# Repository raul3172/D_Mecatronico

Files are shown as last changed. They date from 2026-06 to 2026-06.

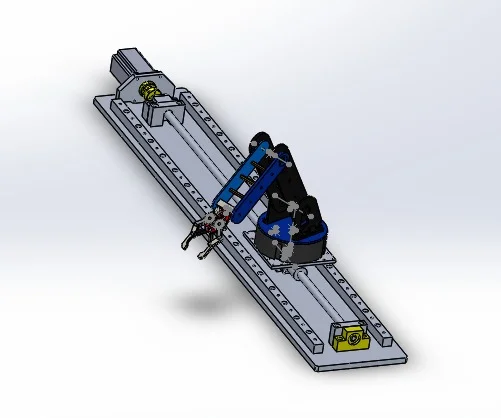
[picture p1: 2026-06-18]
Imagenes/CAD_ROS.webp

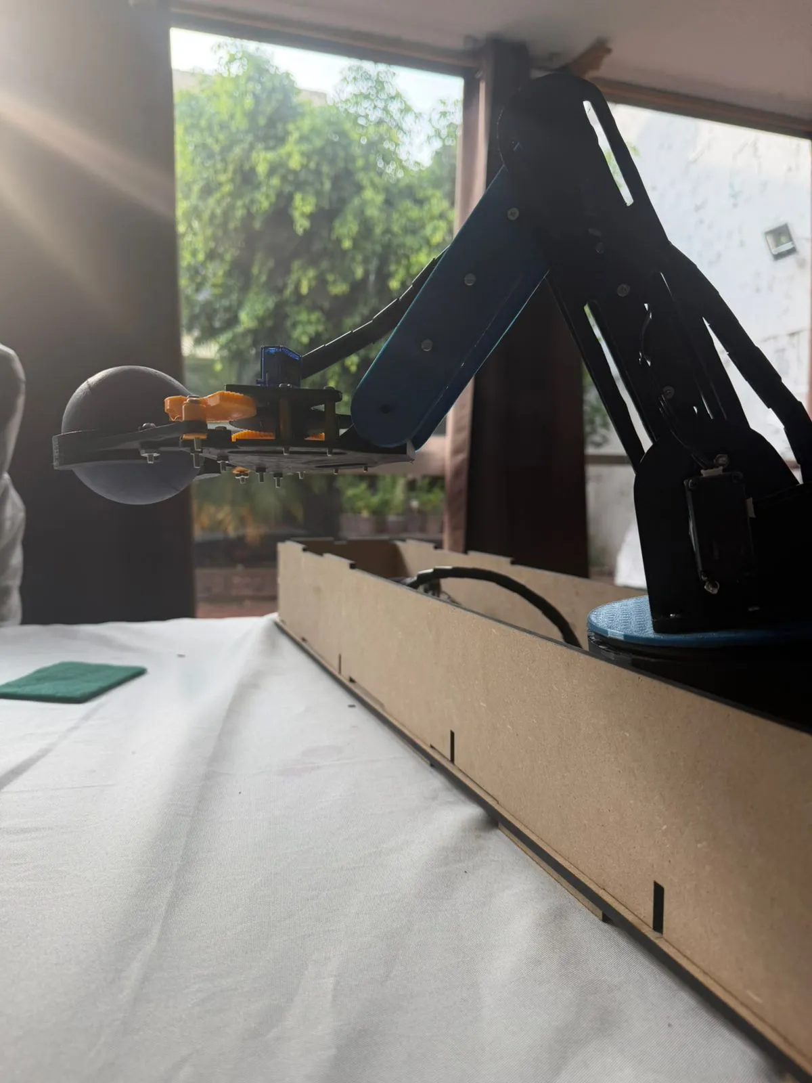
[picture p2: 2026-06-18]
Imagenes/Prototipo.webp

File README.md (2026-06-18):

# Universidad Autónoma de México — Facultad de Ingeniería
## Diseño Mecatrónico
### Brazo Robótico de 4 GDL + Gripper + Base Lineal con Motor a Pasos — Operado en ROS 2
Diseñado y ensamblado por: 
-Fuentes Yañez Ivan
-Garduño Cruz Ingrid Paola
-Huarancca Panana Irvin Daymont
-López Cruz Marino
-Ortíz Martínez Raúl

---

## Tabla de Contenidos

- [Descripción del Proyecto](#descripción-del-proyecto)
- [Arquitectura del Sistema](#arquitectura-del-sistema)
- [Estructura de Archivos](#estructura-de-archivos)
- [Descripción de los Códigos](#descripción-de-los-códigos)
  - [arm_description_v2.xacro](#1-arm_description_v2xacro--descripción-cinemática-del-robot)
  - [arm_controllers.yaml](#2-arm_controllersyaml--configuración-de-controladores)
  - [teach_repeat.py](#3-teach_repeatpy--control-por-terminal-enseñar-y-repetir)
  - [teach_pendant_gui.py](#4-teach_pendant_guipy--interfaz-gráfica-de-control-pyqt5)
  - [IntegradoMotoresYBase.ino](#5-integradomoresybaseino--firmware-esp32-control-de-hardware-real)
- [Interconexión entre Módulos](#interconexión-entre-módulos)
- [Requisitos Previos](#requisitos-previos)
- [Instalación y Configuración](#instalación-y-configuración)
- [Instrucciones para Echar a Andar el Robot](#instrucciones-para-echar-a-andar-el-robot)
- [Control del Robot](#control-del-robot)
- [Solución de Problemas Comunes](#solución-de-problemas-comunes)
- [Notas Técnicas](#notas-técnicas)

---

## Descripción del Proyecto

Este proyecto implementa el control completo de un **brazo robótico serial de 3 grados de libertad (GDL)** montado sobre una **base lineal accionada por motor a pasos**, con un **gripper** al final del efector. El sistema es operado mediante **ROS 2** y puede visualizarse y simularse en **RViz** y **Gazebo**.

### Configuración Física

| Componente | Tipo | Articulación ROS 2 |
|---|---|---|
| Base lineal (riel) | Prismática — traslación en eje Y | `Motor_Base` |
| Hombro | Revoluta | `Motor_1` |
| Codo | Revoluta | `Motor_2` |
| Muñeca | Revoluta | `Motor_3` |
| Gripper | (efector final, no articulado en control) | — |

---

## Arquitectura del Sistema

```
┌─────────────────────────────────────────────────────────────────┐
│                     RASPBERRY PI — ROS 2                        │
│                                                                 │
│  ┌──────────────────┐        ┌───────────────────────────────┐ │
│  │ teach_pendant_   │        │       teach_repeat.py         │ │
│  │    gui.py        │        │   (Control por terminal)      │ │
│  │  (GUI PyQt5)     │        │                               │ │
│  └────────┬─────────┘        └─────────────┬─────────────────┘ │
│           │                                │                   │
│           └───────────────┬────────────────┘                   │
│                           │  publica /joint_states             │
│                           ▼                                    │
│            ┌──────────────────────────┐                        │
│            │     /joint_states topic  │                        │
│            │  sensor_msgs/JointState  │                        │
│            └──────┬───────────────────┘                        │
│                   │                                            │
│        ┌──────────┴──────────┐                                 │
│        ▼                     ▼                                 │
│  ┌──────────────┐    ┌───────────────────┐                     │
│  │ robot_state_ │    │  serial_bridge    │                     │
│  │ publisher    │    │  (nodo ROS 2)     │                     │
│  │ (XACRO/TF)  │    │  espera CALIBRADO │                     │
│  └──────┬───────┘    └────────┬──────────┘                     │
│         │                     │  <riel,h,c,m,g> por UART      │
│         ▼                     │  115200 baud                   │
│  ┌─────────────┐              │                                │
│  │    RViz     │              │                                │
│  │ (simulación)│              │                                │
│  └─────────────┘              │                                │
└───────────────────────────────┼────────────────────────────────┘
                                │  USB/UART serial
                                ▼
┌───────────────────────────────────────────────────────────────┐
│               ESP32 — IntegradoMotoresYBase.ino               │
│                                                               │
│  setup() → ejecutarHoming() → xTaskCreate(tareaMotorPasos)   │
│                                                               │
│  loop() (core 1)              tareaMotorPasos (core 0)        │
│  ├─ Parser serial <...>       └─ stepper.run() + WDT          │
│  └─ procesarTrama()                                           │
│       ├─ moverAMilimetros()  → A4988 → Motor a pasos (riel)  │
│       ├─ radToHiwonder()     → Bus serial → Servos Hiwonder   │
│       │                          ID1:Hombro  ID2:Codo         │
│       │                          ID3:Muñeca                   │
│       └─ servoGripper.write()→ PWM → SG90 (gripper)          │
│                                                               │
│  GPIO 26: FC_INICIO ──── homing                              │
│  GPIO 27: FC_FIN    ──── homing                              │
└───────────────────────────────────────────────────────────────┘
```

---

## Estructura de Archivos

```
robot_arm_ws/
├── src/
│   └── arm_description/
│       ├── urdf/
│       │   └── arm_description_v2.xacro       # Descripción cinemática del robot
│       ├── config/
│       │   └── arm_controllers.yaml           # Configuración de controladores ROS 2
│       ├── launch/
│       │   └── display.launch.py              # Launch para RViz
│       ├── scripts/
│       │   ├── teach_repeat.py                # Control por terminal (enseñar y repetir)
│       │   └── teach_pendant_gui.py           # Control por interfaz gráfica PyQt5
│       ├── meshes/                            # Mallas 3D del robot (.STL/.DAE)
│       ├── package.xml
│       └── CMakeLists.txt
├── firmware/
│   └── IntegradoMotoresYBase/
│       └── IntegradoMotoresYBase.ino          # Firmware ESP32 — control de hardware real
└── README.md
```

---

## Descripción de los Códigos

### 1. `arm_description_v2.xacro` — Descripción Cinemática del Robot

**Propósito:** Define la geometría, cinemática, masa e inercias del robot para ROS 2.

**Contenido principal:**

- **Links** (eslabones): declaran la geometría visual, de colisión y propiedades de masa/inercia de cada pieza física. Las inercias están expresadas en coordenadas **relativas al link**, no globales.
- **Joints** (articulaciones): definen cómo se conectan los links entre sí. Los orígenes están en **metros** y los ángulos en **radianes**.

**Articulaciones definidas:**

| Joint | Tipo | Eje | Rango |
|---|---|---|---|
| `Motor_Base` | `prismatic` | Y | 0.0 – 0.5 m |
| `Motor_1` | `revolute` | Z | −π – +π rad |
| `Motor_2` | `revolute` | Z | −π/2 – +π/2 rad |
| `Motor_3` | `revolute` | Z | −π – +π rad |

> **Nota importante:** Los archivos exportados desde CAD frecuentemente usan milímetros en lugar de metros y coordenadas globales en los orígenes de inercia. Esta versión (`v2`) corrige ambos problemas.

---

### 2. `arm_controllers.yaml` — Configuración de Controladores

**Propósito:** Configura el plugin `ros2_control` para exponer los cuatro joints del robot como un `JointTrajectoryController`.

**Estructura:**

```yaml
controller_manager:
  ros__parameters:
    joint_state_broadcaster:
      type: joint_state_broadcaster/JointStateBroadcaster

    arm_controller:
      type: joint_trajectory_controller/JointTrajectoryController

arm_controller:
  ros__parameters:
    joints:
      - Motor_Base
      - Motor_1
      - Motor_2
      - Motor_3
    command_interfaces: [position]
    state_interfaces: [position, velocity]
```

**Por qué los cuatro joints:** Una configuración incompleta (solo 3 joints) haría que `ros2_control` ignorara `Motor_Base`, dejando la base lineal sin control activo.

---

### 3. `teach_repeat.py` — Control por Terminal (Enseñar y Repetir)

**Propósito:** Nodo ROS 2 en Python que permite al usuario definir posturas del robot ("enseñar") mediante comandos de terminal y luego reproducirlas en secuencia ("repetir").

**Funcionamiento interno:**

```
Usuario escribe postura → Nodo recibe parámetros →
Publica en /joint_states → ros2_control ejecuta movimiento
```

**Características clave:**

- Usa un `dict` (`_pos_map`) para mapear nombre de joint → posición, en lugar de índices fijos. Esto lo hace **robusto ante mensajes `JointState` que lleguen en orden arbitrario**.
- Permite guardar una secuencia de waypoints y reproducirlos en bucle.
- Las posiciones de `Motor_Base` se especifican en **metros** y las de `Motor_1/2/3` en **radianes**.

**Uso básico:**

```bash
ros2 run arm_description teach_repeat.py
# Dentro del nodo:
# > teach   → guarda postura actual
# > repeat  → reproduce todas las posturas guardadas
# > clear   → borra la secuencia
```

---

### 4. `teach_pendant_gui.py` — Interfaz Gráfica de Control (PyQt5)

**Propósito:** Nodo ROS 2 con interfaz gráfica que emula un *teach pendant* industrial: panel de control con sliders para mover cada articulación en tiempo real.

**Funcionamiento interno:**

```
Slider GUI (PyQt5) → callback onChange →
Publica JointState en /joint_states →
robot_state_publisher actualiza TF →
RViz visualiza postura
```

**Características de la GUI:**

| Control | Rango | Unidad |
|---|---|---|
| Slider `Motor_Base` | 0.0 – 0.5 | metros (m) |
| Slider `Motor_1` | −3.14 – +3.14 | radianes (rad) |
| Slider `Motor_2` | −1.57 – +1.57 | radianes (rad) |
| Slider `Motor_3` | −3.14 – +3.14 | radianes (rad) |
| Botón **Teach** | — | Guarda postura actual |
| Botón **Repeat** | — | Reproduce secuencia |
| Botón **Clear** | — | Limpia secuencia |

> Los sliders usan escala interna en enteros y convierten al rango físico al publicar, garantizando precisión y fluidez visual.

---

### 5. `IntegradoMotoresYBase.ino` — Firmware ESP32: Control de Hardware Real

**Propósito:** Firmware que corre directamente en el microcontrolador **ESP32** y actúa como la capa más baja del sistema. Recibe tramas de posición desde la Raspberry Pi (vía `serial_bridge` de ROS 2) y las traduce en movimientos físicos reales de todos los actuadores.

> Este archivo es el **puente entre el mundo ROS 2 (software) y el hardware físico del robot**. Sin él, el sistema solo funciona en simulación.

---

#### Mapa de hardware

| GPIO | Periférico | Función |
|---|---|---|
| 16 (RX2) | Bus serial Hiwonder | Recibir telemetría de servos |
| 17 (TX2) | Bus serial Hiwonder | Enviar comandos a servos |
| 18 | Servo SG90 (gripper) | PWM 50 Hz, 500–2400 µs |
| 25 | Driver A4988 — DIR | Dirección del motor a pasos |
| 33 | Driver A4988 — STEP | Pulsos del motor a pasos |
| 26 | Final de carrera INICIO | Detecta el límite de origen del riel |
| 27 | Final de carrera FIN | Detecta el límite máximo del riel |

---

#### Librerías utilizadas

| Librería | Propósito |
|---|---|
| `LobotSerialServoControl` | Protocolo de bus serial para servos Hiwonder (ID 1, 2, 3) |
| `AccelStepper` | Control suave del motor a pasos con aceleración y desaceleración |
| `ESP32Servo` | Generación de PWM para servo SG90 compatible con ESP32 |
| FreeRTOS (integrado en ESP-IDF) | Multitarea: tarea dedicada al motor en core 0 |

---

#### Flujo de ejecución

```
Encendido del ESP32
       │
       ▼
setup()
  ├─ Inicializa serial, GPIO, servo, stepper y mutex
  └─ ejecutarHoming()          ← bloquea hasta completar calibración
          │
          ├─ Fase 1: avanza hasta FC_FIN  → mide recorrido total
          ├─ Retroceso 3 mm (suelta sensor)
          ├─ Fase 2: regresa hasta FC_INICIO → define posición 0
          ├─ Avance 2 mm (despega del sensor) → redefine cero real
          ├─ Test gripper (0° → 110° → 0°)
          └─ Envía "CALIBRADO" por serial → Raspberry Pi libera ROS 2
               │
               ▼
       xTaskCreatePinnedToCore(tareaMotorPasos, core 0)
               │
               ▼
loop() — core 1 (en paralelo con la tarea)
  └─ Lee serial byte a byte buscando tramas <...>
       └─ procesarTrama() cuando trama válida
```

---

#### Secuencia de Homing — `ejecutarHoming()`

El homing es la **calibración automática de la base lineal** al encender el robot. Es indispensable porque el motor a pasos no tiene encoder: sin homing, el ESP32 no sabe en qué posición está el carro del riel.

```
  INICIO ◄────────────────────────────────────────── FIN
  [FC_INICIO]  2mm ◄── cero real ──► 3mm  [FC_FIN]
     │                                              │
     │← ← ← ← Fase 2: regresa ← ← ← ← ← ← ← ← ←│
     │                                              │
     │─ ─ ─ ─ Fase 1: avanza ─ ─ ─ ─ ─ ─ ─ ─ ─ →│
```

**Pasos detallados:**

1. **Avanza hacia FC_FIN** a velocidad constante (300 pasos/s). Mide cuántos pasos recorre — ese valor es `recorridoMaxPasos`, el límite físico del riel.
2. **Retrocede 3 mm** para soltar el sensor final (evita presión mecánica continua).
3. **Regresa hacia FC_INICIO** a velocidad constante inversa.
4. **Define `currentPosition = 0`** al tocar el inicio.
5. **Avanza 2 mm** para despegar el sensor, luego **redefine ese punto como el nuevo cero**. De esta forma el riel nunca queda presionando un final de carrera.
6. **Test del gripper**: ciclo 0° → 110° → 0° para verificar que el SG90 responde correctamente.
7. **Envía `"CALIBRADO"`** por serial. El `serial_bridge` en la Raspberry Pi espera este mensaje antes de comenzar a enviar tramas de posición, garantizando que ROS 2 y el ESP32 están sincronizados.

> **Decisión de diseño crítica:** La tarea FreeRTOS del motor se crea **después** del homing, no antes. Si se creara antes, la tarea y `ejecutarHoming()` competirían por el stepper simultáneamente (race condition), causando movimientos erráticos o bloqueos del mutex.

---

#### Protocolo de comunicación serial — Formato de trama

La Raspberry Pi envía tramas a **115200 baud** con la siguiente estructura:

```
<riel_m,hombro_rad,codo_rad,muneca_rad,gripper_norm>
```

| Campo | Tipo | Unidad | Ejemplo |
|---|---|---|---|
| `riel_m` | float | metros | `0.235` |
| `hombro_rad` | float | radianes | `1.047` |
| `codo_rad` | float | radianes | `-0.524` |
| `muneca_rad` | float | radianes | `0.000` |
| `gripper_norm` | float | normalizado [0.0–1.0] | `0.750` |

**Ejemplo de trama completa:**
```
<0.235,1.047,-0.524,0.000,0.750>
```

El parser en `loop()` detecta `<` para abrir y `>` para cerrar la trama, valida que tenga exactamente **4 comas** y usa `sscanf()` para parsear los 5 valores flotantes de forma robusta. Tramas malformadas o con ruido se descartan silenciosamente.

**Mecanismo de timeout de trama:** Si transcurren más de 50 ms entre `<` y `>` sin cerrar la trama, el buffer se descarta y se espera la siguiente. Esto protege contra fragmentación del stream serial.

---

#### Flush post-homing — `tramasFlushPendientes`

El `serial_bridge` de ROS 2 opera a ~50 tramas/segundo de forma continua. Durante el homing, ROS 2 sigue enviando la posición objetivo inicial (típicamente `0.46 m` de riel), aunque el robot aún no está calibrado. Si el ESP32 procesara esas tramas residuales inmediatamente después del homing, el motor intentaría ir a `0.46 m` antes de que ROS 2 actualizara su estado.

**Solución:** Se descartan las primeras **150 tramas** post-homing (≈ 3 segundos), suficiente para que ROS 2 termine de procesar la trayectoria de calibración y comience a enviar posiciones válidas.

```cpp
if (tramasFlushPendientes > 0) {
    tramasFlushPendientes--;
    return;   // descarta la trama silenciosamente
}
```

---

#### Conversión de unidades — `radToHiwonder()`

Los servos Hiwonder usan una escala propietaria de **0 a 1000** (donde 500 = centro = 0°). La función convierte radianes a esta escala considerando el límite mecánico de ±120° (±2.0944 rad):

```cpp
int radToHiwonder(float rad) {
    return constrain(500 + (int)(rad * 500.0f / LIM_RAD), 0, 1000);
}
```

| Entrada (rad) | Salida (Hiwonder) | Ángulo físico |
|---|---|---|
| −2.0944 | 0 | −120° (límite izquierdo) |
| 0.0 | 500 | 0° (centro) |
| +2.0944 | 1000 | +120° (límite derecho) |

---

#### Deadband de servos

Para evitar vibraciones y desgaste prematuro de los servos Hiwonder por ruido en la señal de ROS 2, se aplica un **deadband de 4 unidades**: solo se envía un nuevo comando al servo si la posición destino difiere en más de 4 unidades de la última enviada.

```cpp
if (abs(posHombro - lastHombro) > DEADBAND) {
    BusServo.LobotSerialServoMove(ID_HOMBRO, posHombro, MOVE_TIME_MS);
    lastHombro = posHombro;
}
```

---

#### Multitarea FreeRTOS — `tareaMotorPasos()`

El motor a pasos requiere pulsos de STEP muy frecuentes (cada pocos microsegundos a alta velocidad). Si estos pulsos se generaran en `loop()` junto con el parsing serial, las interrupciones del serial retrasarían los pulsos y el motor perdería pasos.

**Solución:** La función `stepper.run()` corre en una **tarea dedicada en el core 0** del ESP32 (core independiente al de `loop()`). El acceso al objeto `stepper` está protegido por un **mutex FreeRTOS** (`stepperMutex`) para evitar que `loop()` y la tarea modifiquen el stepper simultáneamente.

```
Core 0                          Core 1
──────────────────────          ──────────────────────
tareaMotorPasos()               loop()
  └─ stepper.run()                └─ Serial.read()
     (pulsos STEP)                   procesarTrama()
     mutex protege acceso            mutex protege acceso
```

La tarea también alimenta el **Watchdog Timer (WDT)** del core 0 en cada iteración con `esp_task_wdt_reset()`, previniendo reinicios del ESP32 por timeout del watchdog.

---

#### Gripper SG90 — Escala normalizada

El gripper recibe valores normalizados `[0.0, 1.0]` desde ROS 2, que se mapean a `[0°, 110°]` del servo SG90:

```cpp
int grados = constrain((int)round(valores[4] * 110.0f), 0, 180);
servoGripper.write(grados);
```

| Valor ROS 2 | Ángulo SG90 | Estado gripper |
|---|---|---|
| `0.0` | 0° | Cerrado |
| `0.5` | 55° | Medio abierto |
| `1.0` | 110° | Abierto total |

---

#### Instrucciones para cargar el firmware

**Requisitos:**
- Arduino IDE 2.x con soporte para ESP32 (board: `esp32 by Espressif Systems`)
- Librerías instaladas en Arduino IDE:
  - `AccelStepper` (Mike McCauley)
  - `ESP32Servo` (Kevin Harrington)
  - `LobotSerialServoControl` (Lobot / Hiwonder) — instalar manualmente

**Pasos:**

```
1. Abrir Arduino IDE
2. Seleccionar placa: Herramientas → Placa → ESP32 Dev Module
3. Seleccionar puerto: Herramientas → Puerto → /dev/ttyUSB0 (o el que corresponda)
4. Abrir IntegradoMotoresYBase.ino
5. Verificar (Ctrl+R) — debe compilar sin errores
6. Subir (Ctrl+U) — mantener presionado BOOT en el ESP32 si no sube automáticamente
7. Abrir Monitor Serial a 115200 baud
8. Verificar que aparezca "ESP32 ONLINE - Iniciando homing automatico..."
9. Observar secuencia de homing; al final debe aparecer "CALIBRADO"
```

> **Importante:** El `serial_bridge` de ROS 2 (en la Raspberry Pi) **espera el mensaje `"CALIBRADO"`** antes de comenzar a publicar tramas. Si el homing falla o el mensaje no llega, el sistema ROS 2 permanece en espera.

---

## Interconexión entre Módulos

El siguiente diagrama muestra el flujo de datos completo entre todos los archivos del proyecto, desde la interfaz de usuario hasta los actuadores físicos:

```
teach_pendant_gui.py  ──┐
teach_repeat.py         ├──► /joint_states topic
                        │         │
                        │         ├──► robot_state_publisher ──► /tf ──► RViz
                        │         │         (arm_description_v2.xacro)
                        │         │
                        │         └──► serial_bridge (nodo ROS 2)
                        │                   │
                        │         arm_controllers.yaml
                        │         (configura JointTrajectoryController)
                        │
                        └──────────────────────────────────────────────────────┐
                                                                               │
                                                               UART 115200 baud│
                                                                               ▼
                                                         IntegradoMotoresYBase.ino (ESP32)
                                                               │
                                      ┌────────────────────────┼──────────────────────────┐
                                      ▼                        ▼                          ▼
                               A4988 + Stepper          Bus Hiwonder               PWM SG90
                               (riel lineal)      (hombro, codo, muñeca)          (gripper)
```

**Flujo de comunicación paso a paso:**

1. `arm_description_v2.xacro` es parseado al arrancar `robot_state_publisher`, definiendo la geometría y los frames TF del robot.
2. El ESP32 ejecuta el homing automático al encender y envía `"CALIBRADO"` por serial cuando termina.
3. El `serial_bridge` de ROS 2 (en la Raspberry Pi) espera `"CALIBRADO"` antes de empezar a enviar tramas de posición.
4. `teach_repeat.py` o `teach_pendant_gui.py` publican mensajes `sensor_msgs/JointState` en `/joint_states`.
5. `robot_state_publisher` consume `/joint_states` y publica las transformadas TF de cada eslabón.
6. **RViz** suscribe a `/tf` y `/robot_description` para renderizar el robot en 3D (simulación visual).
7. El `serial_bridge` también suscribe a `/joint_states` y convierte cada mensaje en una trama `<riel_m,h_rad,c_rad,m_rad,gripper_norm>` que envía al ESP32 por UART.
8. El **ESP32** recibe la trama, la parsea, convierte unidades y envía comandos directos a cada actuador físico.

---

## Requisitos Previos

### Sistema Operativo
- **Raspberry Pi:** Ubuntu 22.04 LTS (recomendado para ROS 2 Humble)
- **PC de desarrollo / Arduino IDE:** Windows, macOS o Linux

### Software — Capa ROS 2 (Raspberry Pi)
- **ROS 2 Humble Hawksbill** (o superior)
- **Python 3.10+**
- **PyQt5** (para la GUI)
- **Gazebo Fortress** o **Ignition** (para simulación)
- **colcon** (herramienta de compilación de ROS 2)

### Software — Firmware ESP32
- **Arduino IDE 2.x**
- Board support: `esp32 by Espressif Systems` (vía Boards Manager)
- Librerías Arduino:
  - `AccelStepper` (Mike McCauley) — Library Manager
  - `ESP32Servo` (Kevin Harrington) — Library Manager
  - `LobotSerialServoControl` (Hiwonder) — instalación manual desde `.zip`

### Instalación de dependencias ROS 2

```bash
sudo apt update && sudo apt install -y \
    python3-colcon-common-extensions \
    ros-humble-robot-state-publisher \
    ros-humble-joint-state-publisher \
    ros-humble-joint-state-publisher-gui \
    ros-humble-ros2-control \
    ros-humble-ros2-controllers \
    ros-humble-xacro \
    ros-humble-rviz2 \
    python3-pyqt5
```

### Permisos de puerto serial (para comunicación con ESP32)

```bash
sudo usermod -a -G dialout $USER
# Cerrar sesión y volver a entrar para que aplique
```

---

## Instalación y Configuración

### 1. Crear el workspace

```bash
mkdir -p ~/robot_arm_ws/src
cd ~/robot_arm_ws/src
```

### 2. Clonar o copiar el paquete

```bash
# Si tienes el repositorio en GitHub:
git clone https://github.com/<tu_usuario>/arm_description.git

# O copia manualmente la carpeta arm_description/ dentro de src/
```

### 3. Instalar dependencias de ROS 2

```bash
cd ~/robot_arm_ws
rosdep install --from-paths src --ignore-src -r -y
```

### 4. Compilar el workspace

```bash
cd ~/robot_arm_ws
colcon build --symlink-install
```

### 5. Cargar el entorno

```bash
source ~/robot_arm_ws/install/setup.bash

# Agrega esta línea a tu ~/.bashrc para no repetirla cada sesión:
echo "source ~/robot_arm_ws/install/setup.bash" >> ~/.bashrc
```

---

## Instrucciones para Echar a Andar el Robot

Abre **cuatro terminales** separadas. En cada una ejecuta `source ~/robot_arm_ws/install/setup.bash` antes de cualquier comando.

---

### Terminal 1 — Publicar la Descripción del Robot

```bash
source ~/robot_arm_ws/install/setup.bash

ros2 launch arm_description display.launch.py
```

Esto inicia:
- `robot_state_publisher` (carga el XACRO y publica `/robot_description`)
- `RViz` (abre la visualización 3D del brazo)

> Verifica en RViz que el robot aparezca correctamente en el panel 3D. Si ves errores de TF, espera unos segundos a que los demás nodos levanten.

---

### Terminal 2 — Iniciar el Controlador de Joints

```bash
source ~/robot_arm_ws/install/setup.bash

ros2 run controller_manager spawner arm_controller
ros2 run controller_manager spawner joint_state_broadcaster
```

O si usas el launch completo con Gazebo:

```bash
ros2 launch arm_description gazebo.launch.py
```

---

### Terminal 3 — Opción A: Control por Terminal

```bash
source ~/robot_arm_ws/install/setup.bash

ros2 run arm_description teach_repeat.py
```

Comandos disponibles dentro del nodo:

| Comando | Acción |
|---|---|
| `teach` | Guarda la postura actual en la secuencia |
| `repeat` | Reproduce todas las posturas guardadas |
| `clear` | Borra la secuencia de posturas |
| `set <joint> <valor>` | Mueve un joint a una posición específica |

Ejemplo de sesión:

```
> set Motor_Base 0.2
> set Motor_1 1.57
> set Motor_2 -0.5
> teach
> set Motor_1 0.0
> set Motor_2 0.0
> teach
> repeat
```

---

### Terminal 3 — Opción B: Control por Interfaz Gráfica (Teach Pendant)

```bash
source ~/robot_arm_ws/install/setup.bash

ros2 run arm_description teach_pendant_gui.py
```

Se abrirá la ventana de la GUI con:
- **4 sliders** para mover cada articulación en tiempo real
- **Botones Teach / Repeat / Clear** para programar movimientos
- Indicadores numéricos del valor actual de cada joint

> Mueve los sliders y observa el robot actualizarse en RViz simultáneamente.

---

### Terminal 4 — Monitoreo (Opcional)

```bash
# Ver todos los topics activos
ros2 topic list

# Ver los estados de los joints en tiempo real
ros2 topic echo /joint_states

# Ver el árbol de transformadas TF
ros2 run tf2_tools view_frames
```

---

## Solución de Problemas Comunes

### El robot no aparece en RViz
- Verifica que `robot_state_publisher` esté corriendo: `ros2 node list | grep robot_state`
- Asegúrate de que el XACRO no tenga errores: `xacro arm_description_v2.xacro`
- En RViz, confirma que el **Fixed Frame** esté configurado como `base_link` o `world`

### Error: "Could not load description" al parsear el XACRO
- El error más común es tener valores en **milímetros** en lugar de **metros**. Revisa que todos los `<origin xyz="..."/>` usen valores menores a 2.0 para un robot de tamaño normal de laboratorio.
- Las inercias deben estar en coordenadas relativas al link, no globales.

### Los joints no responden al publicar en `/joint_states`
- Verifica que `arm_controllers.yaml` liste los **cuatro joints**: `Motor_Base`, `Motor_1`, `Motor_2`, `Motor_3`.
- Confirma que el controlador esté activo: `ros2 control list_controllers`

### La GUI se abre pero el robot no se mueve
- Verifica que el nodo `robot_state_publisher` esté corriendo en otra terminal.
- Confirma que `/joint_states` tenga publicaciones: `ros2 topic hz /joint_states`

### Error de importación de PyQt5
```bash
pip3 install PyQt5
# o bien:
sudo apt install python3-pyqt5
```

### El ESP32 no aparece como puerto serial
```bash
# Verificar que el sistema detecta el dispositivo
lsusb | grep -i "cp210\|ch340\|ftdi"
ls /dev/ttyUSB*

# Si no aparece, instalar el driver CP2102 (chip USB-UART del ESP32)
sudo apt install linux-modules-extra-$(uname -r)
```

### El homing no termina / el motor no se mueve
- Verificar conexión física de DIR (GPIO 25) y STEP (GPIO 33) al A4988.
- Confirmar que el A4988 tiene tensión de referencia de motor (VMOT) y lógica (VDD) correctas.
- Abrir Monitor Serial a 115200 baud y verificar que aparezca `"HOMING: Iniciando..."`.
- Si el motor zumba pero no gira, la corriente del A4988 puede estar demasiado baja — ajustar el potenciómetro del driver.

### El ESP32 nunca envía "CALIBRADO"
- Verificar que los finales de carrera estén conectados a GPIO 26 (FC_INICIO) y GPIO 27 (FC_FIN) con `INPUT_PULLUP`.
- Probar los finales de carrera con un multímetro: deben dar continuidad al presionarse.
- Si el riel llega al final de carrera pero el ESP32 no lo detecta, verificar que el sensor sea normalmente abierto (NA) — el código espera que el pin lea `HIGH` cuando libre y `LOW` al activarse.

### Los servos Hiwonder no responden
- Verificar que el bus serial use GPIO 16 (RX2) y GPIO 17 (TX2) a 115200 baud.
- Confirmar que cada servo tenga su ID configurado correctamente (ID1: hombro, ID2: codo, ID3: muñeca) usando el software de configuración Hiwonder.
- El bus serial Hiwonder es half-duplex: TX y RX del ESP32 se conectan al mismo cable de datos del servo a través de un resistor o lógica de bus.

### El gripper no se mueve o tiembla
- Verificar que el SG90 esté conectado a GPIO 18.
- El servo necesita alimentación de 5V externa — no directamente del ESP32 (que da 3.3V en sus pines GPIO y capacidad de corriente limitada en 5V).
- Si el servo tiembla en posición fija, reducir el ruido en la señal PWM asegurando que la alimentación del servo tenga un capacitor de desacople (100 µF) cerca del conector.

---

## Notas Técnicas

### Conversión de unidades CAD → ROS 2
Los archivos XACRO exportados directamente desde software CAD (SolidWorks, Fusion 360, etc.) frecuentemente tienen:
- Coordenadas en **milímetros** → deben convertirse a **metros** (dividir entre 1000)
- Orígenes de inercia en **coordenadas globales** → deben expresarse en **coordenadas relativas al link**
- Rotaciones de malla visual incorrectas → corregir solo en `<visual>`, **nunca** en `<joint>` para no afectar la cinemática

### Robustez en lectura de JointState
Los mensajes `sensor_msgs/JointState` no garantizan un orden fijo en el arreglo de nombres y posiciones. Por esta razón, los scripts de control usan un **diccionario** (`_pos_map: {nombre_joint: posición}`) en lugar de acceso por índice, garantizando que cada joint reciba el valor correcto independientemente del orden de llegada.

### Escalado del slider de Motor_Base
La articulación prismática `Motor_Base` opera en metros (rango 0.0–0.5 m), mientras que las articulaciones revoluta operan en radianes (±π). La GUI escala internamente los sliders a sus respectivas unidades físicas para garantizar precisión y una experiencia de control natural.

---

## Licencia

Proyecto académico — Universidad Autónoma de México, Facultad de Ingeniería.  
Uso educativo y de investigación.

---

*Desarrollado con ROS 2 Humble · Python 3 · PyQt5 · XACRO · RViz · Gazebo · ESP32 · Arduino IDE · AccelStepper · FreeRTOS*

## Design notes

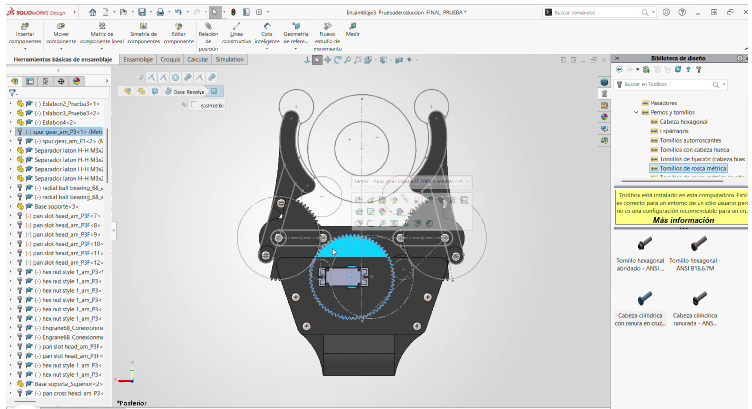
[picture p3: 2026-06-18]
Imagenes/Gripper.webp

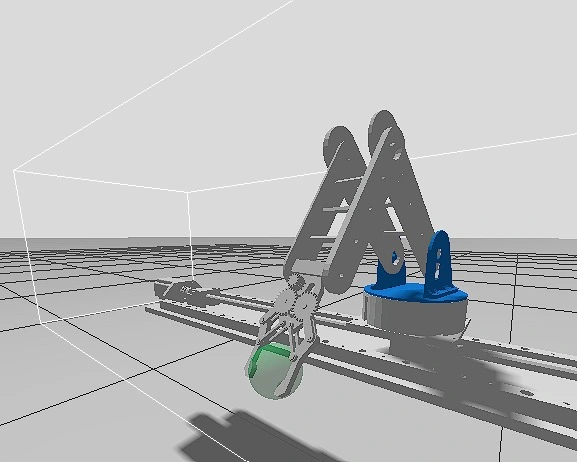
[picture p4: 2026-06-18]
Imagenes/Simulacion.webp

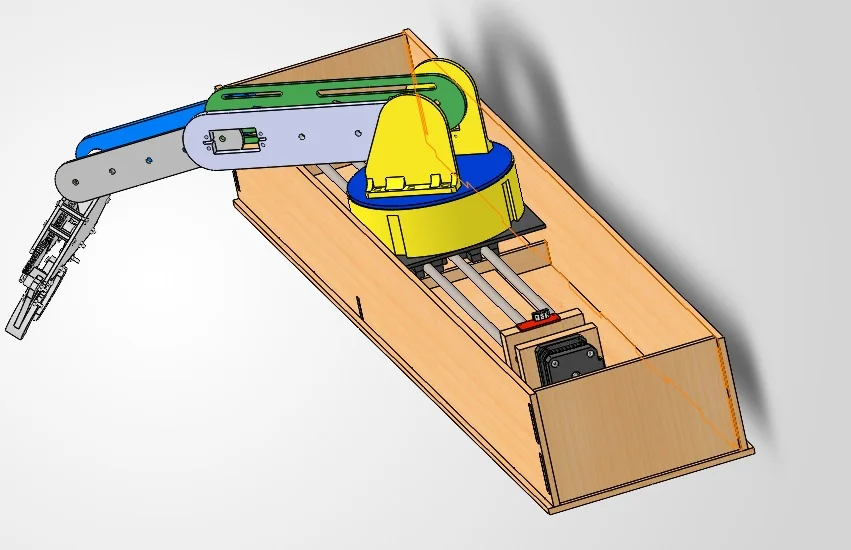
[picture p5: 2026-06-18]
Imagenes/CAD.webp

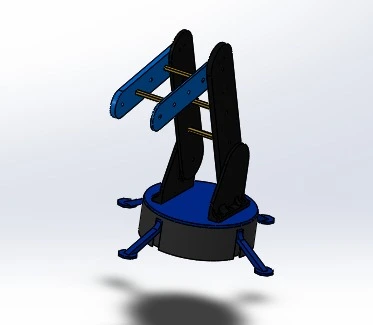
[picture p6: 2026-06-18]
Imagenes/Brazo_CAD.webp

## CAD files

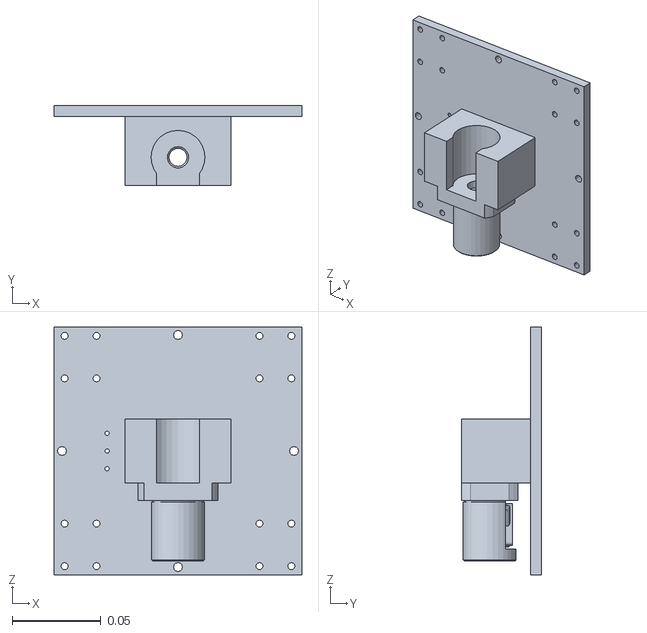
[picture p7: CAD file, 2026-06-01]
src/arm_description/meshes/eje_x.STL
0.14 x 0.0454 x 0.14

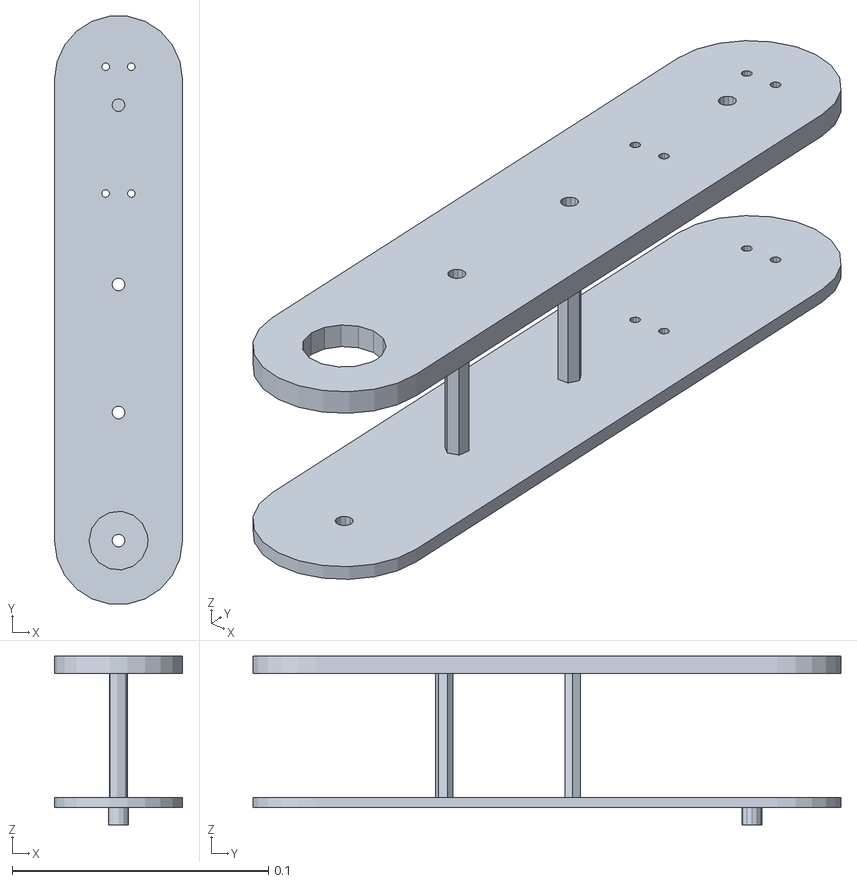
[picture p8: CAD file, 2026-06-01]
src/arm_description/meshes/brazo_base.STL
0.05 x 0.23 x 0.0659

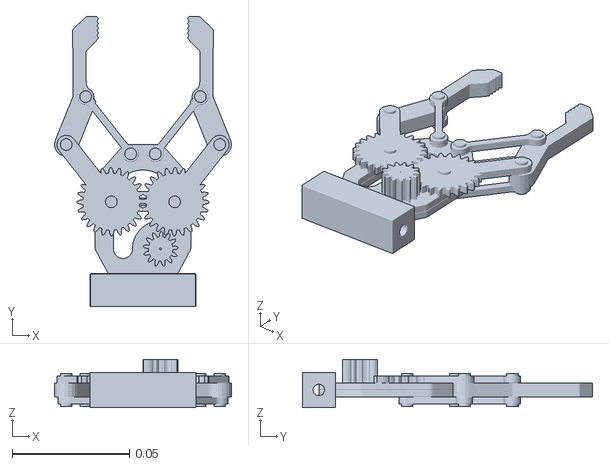
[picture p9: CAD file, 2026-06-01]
src/arm_description/meshes/gripper.STL
0.0753 x 0.123 x 0.0205

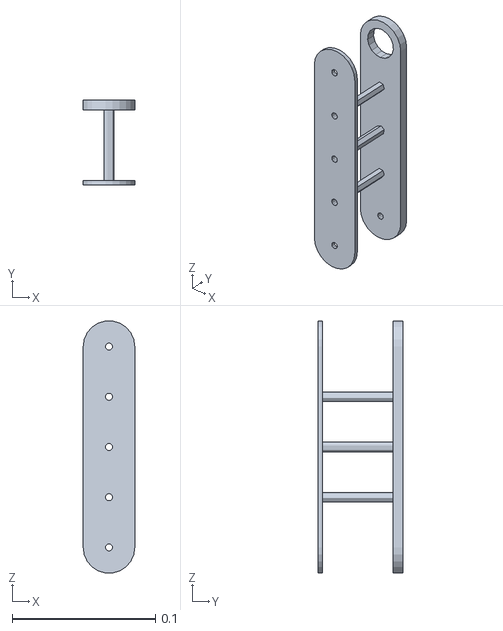
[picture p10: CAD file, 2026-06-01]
src/arm_description/meshes/brazo_gripper.STL
0.036 x 0.0592 x 0.176

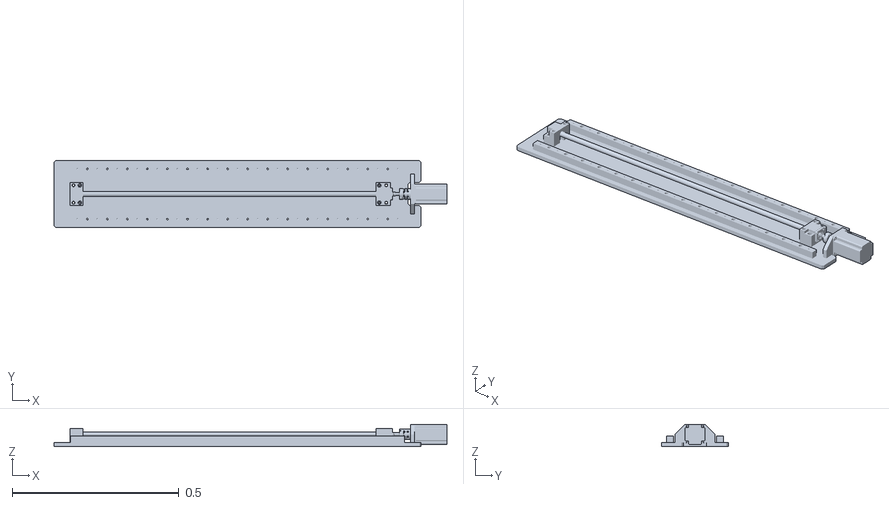
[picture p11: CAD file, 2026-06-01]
src/arm_description/meshes/base_link.STL
1.18 x 0.2 x 0.067

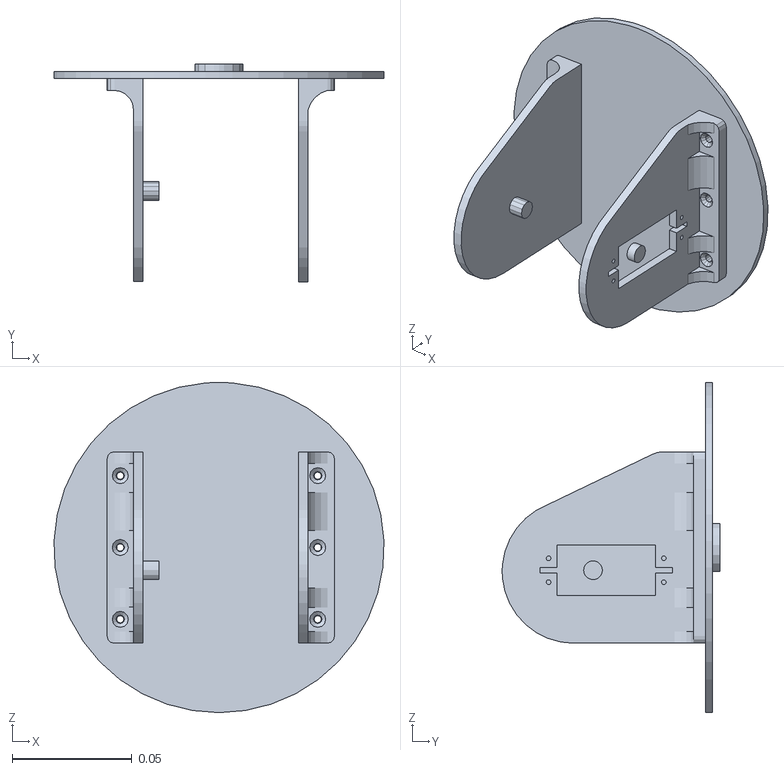
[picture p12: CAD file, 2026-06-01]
src/arm_description/meshes/disco_soportes.STL
0.138 x 0.091 x 0.138

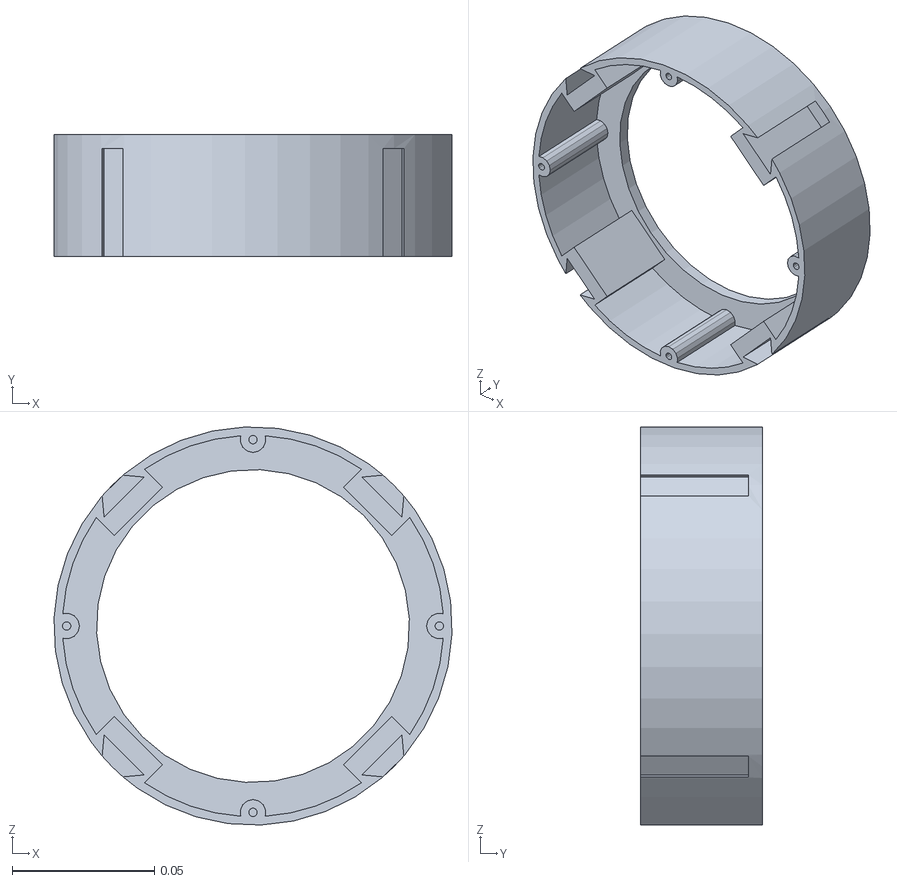
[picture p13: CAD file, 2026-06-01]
src/arm_description/meshes/rotacion_brazo.STL
0.14 x 0.043 x 0.14

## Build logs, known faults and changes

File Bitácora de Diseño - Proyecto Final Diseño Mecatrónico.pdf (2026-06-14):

## Universidad Nacional Autónoma de México

## Facultad de Ingeniería

## División de Ingeniería Mecánica e

## Industrial

## Diseño Mecatrónico

## Grupo 06

## Proyecto Final

## Prototipo de Manipulador Robótico con Base Lineal

## Desplazable

Integrantes:

- Chavez Espinosa Noah Iván
- Cruz Ramírez Dafne Aislinn
- Fuentes Yañez Ivan
- Garduño Cruz Ingrid Paola
- Huarancca Panana Irvin Daymont
- López Cruz Marino
- Ortíz Martínez Raúl
- Rosales Villegas Adair

Profesor: Ing. Ignacio Rangel Fuerte

Semestre 2026-2

### Índice

3.2 Diseño de la Base Lineal: Mecanismo de traslación, guías lineales, y acoplamiento del

3.3 Diseño del Manipulador Robótico (3-DOF): Estructura del brazo, análisis de eslabones y

### 1. Introducción y Definición del Problema

### 1.1 Contexto del Cliente

El presente proyecto surge en respuesta a la creciente necesidad de automatización y optimización en las cadenas de suministro globales. Tomando como caso de estudio y simulacro de aplicación real a los Centros de Distribución de Amazon México, se identificó un área de oportunidad crítica en las estaciones de recepción, clasificación y control de calidad de mercancías.
En un entorno logístico de alta densidad, la velocidad de procesamiento de paquetes y la precisión en la detección de anomalías son factores determinantes para el rendimiento de la planta.

### 1.2 Identificación de Necesidades

Para fundamentar el diseño conceptual bajo la metodología de French, se llevó a cabo un panel de levantamiento de requerimientos entre el Cliente (Representantes operativos de Amazon México), el Ingeniero de Diseño (ID) y el Ingeniero de Automatización (IA). El diálogo técnico permitió estructurar las necesidades del sistema:

- Dinámica Operativa: El cliente externó la urgencia de automatizar el traslado continuo de objetos entre una bandeja de alimentación y una mesa de inspección separadas por una distancia lineal de aproximadamente 30 cm a una altura homóloga, eliminando la manipulación manual que actualmente limita la velocidad de la línea a 20-25 productos por minuto e introduce fallas por fatiga.
- Características de la Carga Útil: El sistema debe poseer la versatilidad de manipular objetos geométricamente diversos de superficies variables (lisas a rugosas), con diámetros nominales concentrados entre los 6 y 8 centímetros, y una masa máxima de diseño de hasta 200 gramos (con capacidad estructural de escalabilidad en etapas iniciales).
- Criterios de Desempeño y Entorno: Se estableció una meta de rendimiento de 20 unidades por minuto con proyección a 30 piezas por minuto en régimen continuo, exigiendo una tolerancia de posicionamiento espacial estricta de ±5 mm. El entorno operativo corresponde a una nave industrial cerrada con temperatura controlada 20∘C a 30∘C y presencia moderada de partículas suspendidas (polvo), requiriendo convivencia segura con operadores humanos y componentes comerciales de fácil sustitución.

### 1.3 Objetivos del Proyecto

- Objetivo General

Diseñar, desarrollar e implementar un prototipo funcional de un manipulador robótico con base lineal desplazable controlado mediante una arquitectura empotrada dual, capaz de emular tareas de inspección de calidad automatizada en un entorno logístico.

- Objetivos Específicos:
1. Desarrollar un sistema de traslación horizontal de alta precisión técnica para la cobertura de un área de trabajo extendida.
2. Diseñar un manipulador articulado de tres grados de libertad (3-DOF) robusto y ligero para el posicionamiento de herramientas de inspección.
3. Implementar un esquema de control distribuido mediante el uso coordinado de una Raspberry Pi 4B (alto nivel / procesamiento) y un microcontrolador ESP32 (bajo nivel / control de actuadores en tiempo real).

### 1.4 Estructura Funcional Global

Siguiendo las directrices del diseño de ingeniería, antes de definir la morfología física del prototipo se estableció la caja negra del sistema, mapeando las transformaciones lógicas desde el estado inicial hasta el estado final del proceso:

- Estado de Entrada: Objeto inerte posicionado en la Estación de Alimentación A.

Diagrama de Flujo de Funciones Internas:

1. Detectar Objeto: Sensado de presencia en la zona de recogida.
2. Sujetar Objeto: Actuación del efector final (gripper) para asegurar la carga sin daño superficial.
3. Transportar Objeto: Activación síncrona del actuador lineal horizontal y las articulaciones angulares del manipulador.
4. Posicionar Objeto: Desaceleración y alineación en la coordenada de destino dentro del margen de tolerancia.
5. Liberar Objeto: Apertura del efector final para deponer la carga.
- Estado de Salida: Objeto posicionado exitosamente en la Estación de Inspección B.

### 2. Especificaciones de Diseño e Ingeniería

### 2.1 Requerimientos del Sistema

Para garantizar el cumplimiento de los objetivos de ingeniería, se estableció una matriz de

especificaciones técnicas categorizadas bajo el enfoque del diseño mecatrónico:

Matriz de especificaciones técnicas

ID | Categoría | Requerimiento Técnico | Métrica / Criterio de Aceptación
REQ-MEC-01 | Mecánica | Estructura del Manipulador | Configuración de 3 Grados de Libertad (Articulado).
REQ-MEC-02 | Mecánica | Sistema de Traslación | Actuador lineal de accionamiento por husillo o banda acoplada.
REQ-ELE-01 | Electrónica | Arquitectura de Control | Control dual jerárquico: Procesamiento en Raspberry Pi 4B y ejecución en ESP32.
REQ-ELE-02 | Electrónica | Regulación de Voltaje | Aislamiento y protección de etapas de potencia mediante convertidores Buck XL4015.
REQ-CTR-01 | Control | Control Lineal | Posicionamiento preciso de la base mediante motor con encoder o lazo abierto de alta resolución (motor a pasos con driver A4988).
REQ-CTR-02 | Control | Control de Articulaciones | Uso de servomotores inteligentes con retroalimentación o comunicación serial activa.

Hoja de Especificaciones Técnicas

Parámetro de Diseño | Valor Marginal Aceptable | Valor Objetivo Ideal
Masa de la Carga Útil | 200 g | 1000 g (Margen de Seguridad)
Distancia de Traslado Horizontal | 30 cm | 50 cm
Precisión de Posicionamiento | ±10 mm | ±5 mm
Tiempo de Ciclo por Unidad | ≤ 3s | ≤ 1s

Límite de Presupuesto | $2,500 MXN | $2,000 MXN
Modo de Operación | Semiautónomo | Automatizado Autónomo Cíclico

### 2.2 Matriz de Selección Alternativas

Para la arquitectura del brazo robótico, el equipo evaluó tres conceptos de diseño bajo un análisis ponderado de criterios técnicos (donde 1 es deficiente y 5 es excelente):

- Concepto A (Manipulador Cartesiano en Base Fija): Alta precisión, pero volumen de trabajo severamente restringido y nula flexibilidad angular.
- Concepto B (Manipulador SCARA): Excelente velocidad para pick-and-place horizontal, pero limitado alcance en el eje vertical Z para inspecciones tridimensionales complejas.
- Concepto C (Manipulador Articulado 3-DOF sobre Actuador Lineal): Seleccionado. Ofrece el mejor compromiso entre volumen de trabajo extendido (gracias al eje lineal horizontal) y versatilidad de orientación de las cámaras o sensores mediante los eslabones rotativos.

Matriz de Selección Alternativas

Criterio de Selección | Peso | Concepto A | Concepto B | Concepto C (Seleccionado)
Espacio de trabajo útil / Alcance | 30% | 2 (0.6) | 3 (0.9) | 5 (1.5)
Destreza y flexibilidad angular | 25% | 1 (0.25) | 3 (0.75) | 4 (1.0)
Facilidad de manufactura y ensamble | 20% | 4 (0.8) | 3 (0.6) | 3 (0.6)
Complejidad de los algoritmos de control | 15% | 5 (0.75) | 4 (0.6) | 3 (0.45)
Costo de implementación de hardware | 10% | 3 (0.3) | 2 (0.2) | 3 (0.3)

Total Ponderado | 100% | 2.70 | 3.05 | 3.85

### 3. Diseño Mecánico y Estructural

### 3.1 Criterios de Selección de Materiales y Manufactura

La determinación del material para los eslabones estructurales del brazo y los carros de la base lineal se sometió a un análisis de compromiso (trade-off) entre rigidez, peso, costo y viabilidad de manufactura:

- Aluminio: Evaluado inicialmente por su excelente resistencia mecánica y nula deflexión ante cargas de flexión. No obstante, se descartó debido a que su elevada densidad incrementaba la inercia rotacional del manipulador, exigiendo torques superiores a los provistos por los servos Hiwonder, aunado al alto costo del material y la necesidad de maquinado CNC externo.
- MDF y Acrílico: Considerados opciones viables debido a su bajo costo y ligereza estructural adecuada para manipular cargas de hasta 200 g. Sin embargo, el tiempo logístico requerido para el corte por láser a través de proveedores externos comprometía el cronograma de entrega del proyecto.
- TPU y PLA (Seleccionados): Se optó de manera definitiva por la combinación de polímeros procesados mediante Manufactura Aditiva (Impresión 3D). El uso de impresoras de tecnología FDM dentro del equipo permitió la fabricación inmediata e iterativa de las piezas. Esta tecnología confirió ventajas estructurales críticas: se configuraron patrones de infarto (infill) internos específicos (como patrones giroidales al 20% o 30%) para optimizar la relación resistencia-peso, reforzando las zonas de alta concentración de esfuerzos (como los alojamientos de los servomotores y los rodamientos MR73 y 1906) sin aumentar el peso total de la estructura móvil.
Componente Estructural | Cantidad | Especificación de Catálogo | Asociación a Plano Técnico
Servomotor Inteligente Hiwonder HTS-35H | 3 | Bus Serial, Torque $\ge$ 15 kg·cm | Servo Hiwonder HTS-35H (Plano)
Ventilador Dual de Enfriamiento | 1 | Cojinete de bolas, 5V DC (25x50mm) | Ventilador dual para Raspberry (Plano)
Rodamiento Rígido de Bolas 1906 | 1 | Diámetro Interno: 6mm | Rodamiento 1906 (Plano)

Rodamiento de Precisión de Bolas MR73 | 2 | Alta velocidad, bajo rozamiento | Rodamiento MR73 (Plano)
Tornillería Allen M3 x 12mm | 16 | Acero aleado, ISO 4762 | Tornillos M3 (Plano)
Tornillería Allen M3 x 20mm | 15 | Acero aleado, ISO 4762 | Tornillos M3 (Plano)
Postes de Soporte Hexagonales (30mm) | 8 | Separador macho-hembra latón/aluminio | Elementos de Fijación (Plano)
Postes de Soporte Hexagonales (20mm) | 8 | Separador macho-hembra latón/aluminio | Elementos de Fijación (Plano)

### 3.2 Diseño de la Base Lineal: Mecanismo de traslación, guías lineales, y

acoplamiento del motor.

Conceptualmente, se consideró usar repuestos de impresoras 3D para armar el riel, ya que ofrecen varias características deseables para el desarrollo del proyecto; la disponibilidad de estos elementos ayudaría a reducir tanto los costos como los tiempos de entrega, mientras que su amplio uso ofrece una amplia documentación que facilitaría el diseño de un riel base usando estos componentes.

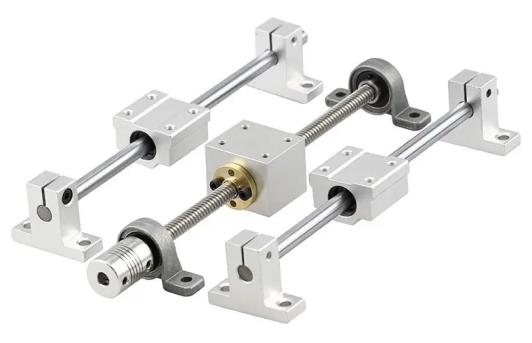
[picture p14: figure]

Figura 1. Propuesta de riel.

Sin embargo, dada la falta de necesidad de personalizar éste elemento en específico, se eligió un riel prefabricado que ya estaba disponible para evitar tiempos de espera y costos extra.

También se consideró brevemente la idea de añadir una ‘mesa’ para cargar con el riel y el brazo. Esta idea fue descartada debido a que era innecesaria.

Figura 2. Propuesta base para el riel.

### 3.3 Diseño del Manipulador Robótico (3-DOF): Estructura del brazo, análisis de

eslabones y articulaciones.

El brazo manipulador está diseñado con 3 grados de libertad (cintura, hombro y codo). La 1ra articulación (cintura) une a la base con la plataforma del riel y le permite rotar sobre el eje Z, otorgando al brazo un rango de manipulabilidad mayor. La 2da articulación (hombro) une al eslabón inferior con la base y permite una rotación sobre el eje X. La 3ra articulación (codo) une al eslabón superior del brazo con el inferior, permite una rotación sobre el eje X e incluye un gripper en el extremo opuesto del eslabón superior.

Figura 3. Ensamble general del manipulador robótico de

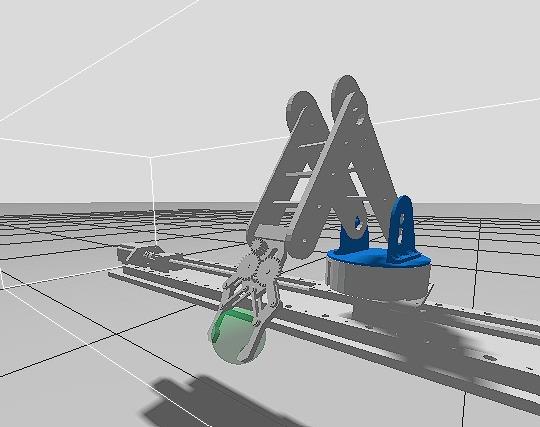
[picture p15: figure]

### 3 GDL y su base lineal de traslación

### 4. Arquitectura de Hardware y Electrónica

### 4.1 Diagrama de Bloques del Sistema. Etapa de Potencia y Regulación

La estabilidad del sistema eléctrico se fundamenta en una estrategia de división de cargas y desacoplamiento de ruidos parásitos. Para garantizar un flujo de corriente continuo y proteger las etapas lógicas contra caídas súbitas de voltaje (brownouts), la red de distribución eléctrica se estructuró a partir de una fuente de alimentación principal de 12V DC distribuida de la siguiente manera:

- Alimentación Directa de 12V: La línea primaria de 12V se rutea de forma directa hacia el bus de alimentación de potencia del driver A4988 (encargado de energizar el motor a pasos del riel lineal) y hacia el bus de alimentación en cascada de los servomotores inteligentes Hiwonder HTS-35H acoplados a las tres articulaciones principales del brazo (Cintura, Hombro y Codo). Esto asegura que la alta demanda de corriente y los picos de torque de los actuadores principales no afecten la instrumentación del sistema.
- Módulo Convertidor Buck XL4015 N.° 1 (Etapa de Cómputo): Se integra un regulador DC-DC Step-Down calibrado a un voltaje de salida constante de 5.0V DC. Este canal se dedica de manera exclusiva a energizar la electrónica digital de control, suministrando la potencia requerida en paralelo por la computadora embebida Raspberry Pi 4B y la placa de desarrollo microcontroladora ESP32.
- Módulo Convertidor Buck XL4015 N.° 2 (Etapa de Efector Final y Seguridad): Se implementa un segundo regulador DC-DC Step-Down aislado, calibrado a una salida regulada de 6.0V DC. Este ramal independiente provee energía dedicada al funcionamiento del motor del efector final (gripper) encargado de la manipulación mecánica de las piezas, aislando magnética y eléctricamente sus conmutaciones lógicas de la etapa de cómputo, alimentando en paralelo las líneas de detección de los interruptores de límite de carrera (limit switches) analógicos situados en los extremos del riel lineal.

### 4.2 Tabla de Componentes (BOM)

A continuación, se tabula el listado consolidado de los elementos del sistema asociados a sus planos mecánicos correspondientes:

Tabla de Componentes Estructurales y Electrónicos

Componente | Cantidad | Referencia de Datasheet | Asociación a Plano Técnico
Raspberry Pi 4B | 1 | RP-008341-DS-1-r | Raspberry PI4B (Plano)
ESP32 (30 Pines, USB-C) | 1 | esp32_datasheet_en.pdf | ESP32 - 30 PINES USB-C (Plano)
Driver A4988 | 1 | A4988_Allegro.pdf | DRIVER A4988 (Plano)
Conversor Buck HW-064 XL4015 | 2 | XL4015_datasheet.pdf | HW-064 XL4015 (Plano)
Hiwonder HTS-35H Servomotores | 3 | HTS-35H_Specifications | Servo Hiwonder HTS-35H (Plano)
Rodamiento Rígido 1906 | 1 | TechnicalSheet-1906 | Rodamiento 1906 (Plano)
Rodamiento de Bolas MR73 | 2 | S1348b09b741a4_MR73 | Rodamiento MR73 (Plano)
Tornillería M3 (12mm / 20mm) | 31 | ISO 4762 Standard | Tornillos M3 (Plano)
Postes de Soporte Metálico | 16 | 30mm y 20mm Hex Spacers | Elementos de Fijación (Plano)

### 4.2 Modelo de Costos de Materiales Directos (BOM Financiero)

El desarrollo del prototipo mecatrónico se rigió bajo una estricta política de optimización presupuestaria, seleccionando componentes comerciales listos para usar (Off-The-Shelf) y procesos de manufactura internos para cumplir con la restricción económica de $2,000.00 MXN establecida en la fase de levantamiento de requerimientos.

Id | Componente / Descripción | Cantidad | Costo Unitario (MXN) | Costo Total (MXN)
1 | Tarjeta de Procesamiento Raspberry Pi 4B | 1 | $0.00* | $0.00
2 | Microcontrolador ESP32 (30 pines, USB-C) | 1 | $140.00 | $140.00
3 | Servomotor Inteligente Hiwonder HTS-35H | 3 | $280.00 | $840.00
4 | Módulo Controlador de Motor a Pasos Driver A4988 | 1 | $45.00 | $45.00
5 | Conversor DC-DC Step-Down Buck XL4015 (5A) | 2 | $65.00 | $130.00
6 | Rodamiento Rígido de Bolas (Modelo 1906) | 1 | $55.00 | $55.00
7 | Rodamiento de Precisión de Bolas MR73 | 2 | $20.00 | $40.00
8 | Filamento TPU / PLA para Impresión 3D (Aprox. 450g) | 1 | $350.00** | $350.00
9 | Kit de Tornillería Metálica M3 (12mm y 20mm) | 31 | $1.50 | $46.50
10 | Postes de Soporte Hexagonales Metálicos (20mm y 30mm) | 16 | $4.00 | $64.00
11 | Sistema de Ventilación Dual 25x50mm para CPU | 1 | $75.00 | $75.00
- | Total Acumulado de Materiales Directos | - | - | $1,785.50

### 5. Arquitectura de Software y Control

La operación del sistema robótico se rige por un entorno de software jerárquico y distribuido que descompone las tareas de planificación global y la ejecución de movimientos físicos. Esta configuración permite procesar los algoritmos computacionales de alto nivel de manera independiente a las rutinas de control deterministas y en tiempo real encargadas de la activación de los actuadores.

### 5.1 Estructura del Repositorio de Control

El entorno de desarrollo y software se centraliza en un espacio de trabajo de ROS2 estructurado bajo el paquete unificado arm_description. Esta organización permite integrar en un mismo repositorio el modelado virtual, los entornos de simulación y los algoritmos de control físico distribuidos en los siguientes directorios raíz:

- /urdf y /meshes: Contienen el archivo descriptivo cinemático y dinámico del robot (arm_description.xacro) junto con los archivos de malla tridimensional (.STL) de cada eslabón (tales como base_link.STL, eje_x.STL, rotacion_brazo.STL y gripper.STL), permitiendo la correcta visualización, mapeo de colisiones e interpretación geométrica en la herramienta Rviz2.
- /config y /launch: Alojan los archivos de parametrización de las articulaciones y perfiles de control (arm_controllers.yaml), así como los scripts de lanzamiento en Python que aíslan los entornos virtuales de prueba (gazebo.launch.py) de la ejecución directa en el hardware real del sistema (real_robot.launch.py).
- /scripts: Módulo crítico de software que ejecuta la lógica operativa del manipulador mediante tres nodos fundamentales programados en Python:
1. serial_bridge.py: Nodo que actúa como puente de comunicación; se suscribe a los tópicos de trayectorias de ROS2, empaqueta los comandos angulares calculados para las articulaciones y las distancias del riel, y los transmite vía puerto serie hacia el microcontrolador ESP32 mediante una trama delimitada.
2. teach_pendant_gui.py: Interfaz gráfica de usuario (GUI) que funge como consola de aprendizaje (Teach Pendant), permitiendo al operador manipular manualmente cada articulación, el riel de traslación y el efector final, facilitando el monitoreo visual del estado de los motores.
3. teach_repeat.py: Nodo encargado de la automatización cíclica, el cual almacena las secuencias de coordenadas y trayectorias previamente grabadas por el usuario para reproducirlas de forma continua, emulando con precisión la rutina operativa en la línea de producción.

### 5.2 Control de Bajo Nivel y Firmware del ESP32

El control determinista y la ejecución física en tiempo real de las trayectorias se coordinan directamente en el microcontrolador ESP32 mediante un firmware estructurado en C++. El sistema opera bajo un esquema de lazo abierto con procesamiento síncrono y decodificación de caracteres guía. La función principal de este firmware consiste en actuar como una capa de abstracción de hardware (Hardware Abstraction Layer o HAL), recibiendo las tramas asíncronas de alta frecuencia desde el nodo puente serial_bridge.py en la Raspberry Pi 4B y traduciendo los valores flotantes directamente en pulsos, comandos por bus serial o señales PWM para excitar los 5 motores del manipulador de forma síncrona.

La secuencia operativa y el procesamiento lógico implementado dentro del script embebido se segmenta detalladamente en los siguientes módulos fundamentales:

### 1. Inicialización y Configuración de Buses de Comunicación (setup)

Al arrancar el sistema, el microcontrolador configura sus periféricos lógicos a través de dos interfaces seriales de hardware independientes:

- Enlace Superior (Computación): El puerto serie por defecto (Serial nativo USB-C) se inicializa a una velocidad de 115,200 baudios. Este canal se vincula directamente al hilo emisor de la Raspberry Pi 4B para capturar la ráfaga de comandos cinemáticos a una tasa de refresco síncrona programada a 300 Hz.
- Enlace Inferior (Actuadores Inteligentes): El segundo puerto de hardware (Serial1) se parametriza de forma asíncrona a 1,000,000 baudios (1 Mbps) empleando los canales GPIO 16 (RX) y GPIO 17 (TX). A través de la librería especializada <SCServo.h>, este bus se conecta directamente a la red en cascada de los servos inteligentes (familia Feetech/Hiwonder STS3215), direccionando las tramas de control en bloque por medio de identificadores físicos precargados (MOTOR_1_ID para el hombro, MOTOR_2_ID para el codo y MOTOR_3_ID para la muñeca).
- Configuración I/O del Riel y Efector: En paralelo, se declaran como salidas digitales estables los pines de control para el driver del actuador lineal (es decir, las señales de dirección DIR y pulsos discretos STEP orientados al circuito integrado A4988), mientras que los pines de entrada asociados a los interruptores de límite axial (limit switches) se configuran con de resistencias de pull-up para atender de manera inmediata las interrupciones de seguridad.

### 2. Algoritmo de Captura y Desempaquetado no Bloqueante (loop)

La rutina cíclica principal ejecuta una evaluación periódica sobre el buffer de entrada del puerto USB para prevenir retardos analógicos. Cuando existen bytes disponibles, el algoritmo lee los caracteres de forma secuencial hasta encontrar un salto de línea ( \n ), utilizando los delimitadores rígidos < y > como firmas de validación estructural.

Una vez que la trama es considerada válida, el firmware ejecuta una subrutina de segmentación por comas (indexOf y substring) aislando dinámicamente las subcadenas para convertirlas a variables numéricas de punto flotante de precisión simple (toFloat()). Este proceso desglosa la cadena recibida en las cinco variables físicas que requiere el manipulador para completar la tarea cinemática:

Trama extraída de /joint_states = (V1, V2, V3, V4, V5

)

Donde de manera estricta:

- V1 = moviento_en_x (Posición deseada del riel de traslación en metros).
- V2 = disco_soportes_rotacion (Ángulo para la articulación del hombro en radianes).
- V3 = brazo_motores (Ángulo para la articulación del codo en radianes).
- V4 = brazo_gripper_azul (Ángulo para la articulación de la muñeca en radianes).
- V5 = gripper_mecanismo (Apertura de la pinza mecánica en radianes).

### 3. Rutinas de Traducción Cinemática y Conducción de Motores

Inmediatamente después de consolidar las variables angulares y lineales, el script invoca la función interna de distribución de movimiento, la cual procesa y discrimina las señales hacia tres etapas físicas diferenciadas que actúan en paralelo:

- Control del Mecanismo del Riel (Actuador Lineal): La variable métrica V1 se procesa mediante un factor de conversión que traduce la distancia a un número absoluto de pasos discretos equivalentes para el motor a pasos, considerando el paso de la banda síncrona o husillo. El firmware evalúa el signo del diferencial respecto a la posición previa para conmutar el estado del pin DIR y genera un bucle temporizado de flancos de subida y bajada en el pin STEP para excitar el driver A4988. Antes de conmutar los flancos, se valida de forma síncrona el estado de los interruptores de límite; si la trayectoria intenta rebasar la cota física permitida, el pulso se inhibe inmediatamente en esa dirección como método de protección contra colisiones mecánicas.
- Control del Brazo Articulado (Servos de Bus Serial): Las variables angulares en radianes correspondientes al hombro (V2), codo (V3) y muñeca (V4) son sometidas a un mapeo lineal matemático para transformarlas a la resolución discreta de los encoders absolutos de los servos (escala nativa de 0 a 4095 pasos, fijando la posición central de 0.0 radianes exactamente en el setpoint intermedio de 2048 pasos). Para asegurar una respuesta fluida y síncrona, las tres posiciones se empaquetan en un arreglo indexado de posición y se transmiten al bus de 1 Mbps utilizando la función nativa de escritura en bloque de la librería Feetech: sts_servos.SyncWritePosEx(ID, 3, Position, Speed, ACC);

Al programar los arreglos de velocidad (Speed) y aceleración (ACC) en valores de cero, el firmware deshabilita las rampas de interpolación internas de los servos, forzándolos a alcanzar el setpoint de forma inmediata y permitiendo que sea la Raspberry Pi 4B (desde el entorno ROS 2) quien gobierne la suavidad del movimiento a través del polinomio cinemático continuo de quinto orden ya calculado.

- Control del Efector Final (Gripper): La última variable desempaquetada V5 se convierte de radianes a un ciclo de trabajo (duty cycle) de modulación por ancho de pulsos (PWM). Esta señal de control se inyecta directamente al servo convencional de la pinza mecánica, modificando la apertura angular de sus mordazas. La limitación por software (constrain) asegura que el gripper ejerza la fuerza necesaria para sujetar firmemente los componentes en el proceso de inspección, evitando rebasar el umbral de deformación o fatiga mecánica sobre la estructura del efector impresa con filamento flexible (TPU).

### 4. Bucle de Retroalimentación de Datos hacia ROS 2 (Feedback Loop)

Finalmente, tras direccionar las señales a los actuadores, el script lee variables internas de estado del microcontrolador o de telemetría de los motores y construye una cadena de texto de confirmación. Esta cadena es transmitida de vuelta a la Raspberry Pi 4B mediante la instrucción Serial.println(), donde el nodo ejecutor serial_bridge.py captura la respuesta asíncrona dentro de su hilo secundario (_read_loop) y la publica de manera inmediata en el tópico de diagnóstico /esp32/feedback, cerrando el ciclo completo de supervisión de hardware.

### 6. Resultados, Conclusiones y Trabajo Futuro

### 6.1 Resultados y Evidencias de Operación

Tras la integración física de los subsistemas, el despliegue del firmware en el microcontrolador ESP32 y la sincronización con el entorno ROS2, se sometió al prototipo a un conjunto de pruebas funcionales en condiciones críticas de operación para validar la estabilidad y velocidad de la arquitectura mecatrónica. En primera instancia, las pruebas de desempeño y sincronización cinemática de alta frecuencia demostraron que el algoritmo de parseo y conversión en lazo abierto dentro del ESP32 ofrece una respuesta altamente fluida y determinista, ya que el nodo puente serial_bridge.py ejecutado en la Raspberry Pi 4B logró transmitir tramas periódicas

continuas a una frecuencia de 300 Hz a través del bus serial de 115,200 baudios sin registrar pérdidas de paquetes, desbordamientos de memoria o saturación del buffer.

Asimismo, el comportamiento dinámico de las articulaciones comprobó que los actuadores responden con precisión milimétrica a los comandos de posición en radianes mapeados desde el tópico /joint_states. Al deshabilitar las rampas internas de velocidad y aceleración de los

servos inteligentes Hiwonder, la trayectoria física de los eslabones rotacionales

## disco_soportes_rotacion, brazo_motores y brazo_gripper_azul replicó con

absoluta fidelidad las curvas continuas generadas por los polinomios cinemáticos de quinto orden calculados en ROS2, eliminando desfases temporales.

Por otra parte, la operación de la base lineal y sus sistemas de seguridad pasiva validaron el correcto mapeo del driver A4988, el cual tradujo la variable métrica axial moviento_en_x en

trenes de pulsos estables para el motor a pasos, permitiendo desplazamientos lineales homogéneos a lo largo del riel, mientras que los interruptores de límite de carrera analógicos situados en los extremos respondieron de forma síncrona, interrumpiendo inmediatamente los flancos de subida del pin STEP al activarse para proteger físicamente la estructura. Finalmente, la validación de la pinza mecánica demostró que la conversión de la variable gripper_mecanismo a señales PWM dedicadas de 6.0V DC permitió un control firme de las

mordazas del efector final, cuya estructura impresa en filamento flexible absorbió con éxito los impactos elásticos durante la sujeción de los componentes de prueba sin presentar fatiga mecánica ni sobrecalentamiento en el servomotor.

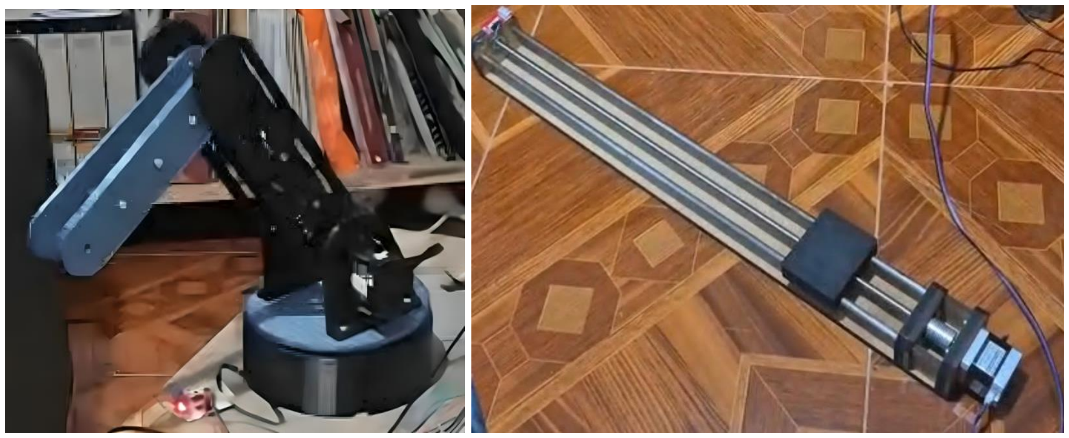
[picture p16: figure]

Figura 4. Prototipo funcional del manipulador robótico y la base lineal.

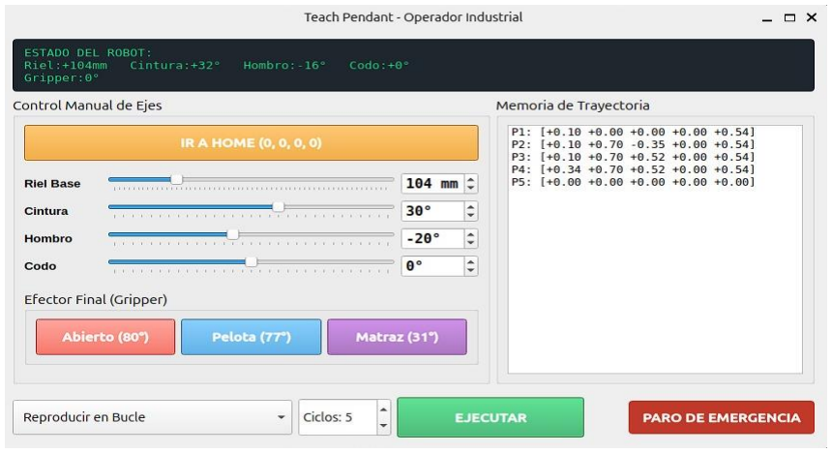
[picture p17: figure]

### 6.2 Conclusiones del Proyecto

Los resultados experimentales permitieron consolidar la bitácora técnica demostrando, en primer lugar, la alta eficacia de la arquitectura de control dual jerárquica implementada en el sistema. Dividir las tareas computacionales bajo un esquema maestro-esclavo, donde la Raspberry Pi 4B asume el procesamiento lógico pesado y la planificación global mientras el microcontrolador ESP32 ejecuta el control determinista de los actuadores en tiempo real, resultó ser la estrategia óptima para evitar que los algoritmos de software interfieran con la generación crítica de pulsos y la conmutación de las señales de potencia. En el ámbito eléctrico, el desarrollo validó plenamente la necesidad de implementar una robusta estrategia de segmentación de energía a través de los módulos convertidores Buck XL4015 independientes, ya que al separar la red lógica dedicada a las tarjetas de cómputo a 5.0V DC de la red electromecánica dedicada a la pinza y sensores a 6.0V DC, se mitigaron por completo los ruidos electromagnéticos parásitos y se eliminó de raíz el riesgo de fallas por caídas súbitas de voltaje causadas por los picos de torque de los motores.

De igual manera, las evidencias recolectadas en las pruebas funcionales ratificaron que la selección de la configuración geométrica del manipulador, consistente en un brazo articulado de tres grados de libertad montado sobre un eje de traslación lineal horizontal, fue la decisión de diseño más acertada. Esta distribución estructural expande de forma significativa el espacio de trabajo efectivo del robot y le otorga una versatilidad angular superior, cualidades que resultan indispensables para emular con alta fidelidad y dinamismo las tareas tridimensionales de posicionamiento espacial e inspección automatizada que demanda una estación de control de calidad en un entorno industrial real.

### 6.3 Trabajo Futuro

Con el propósito de elevar la madurez tecnológica del prototipo hacia una etapa de aplicación industrial avanzada, se plantea a futuro sustituir el motor a pasos del riel axial por un motor de corriente directa o un actuador con encoder acoplado de lazo cerrado, permitiendo al ESP32 corregir dinámicamente errores por holgura mecánica o deslizamiento de la banda mediante retroalimentación posicional en tiempo real. Asimismo, se proyecta aprovechar la capacidad de procesamiento remanente en la Raspberry Pi 4B para implementar un sistema de visión artificial activa conectando una cámara en el efector final bajo el entorno ROS2, lo que habilitará funciones autónomas de reconocimiento óptico de caracteres, detección de fallas superficiales y clasificación de componentes. Finalmente, se contempla la migración hacia un control por fuerza adaptativo en el gripper instrumentando sus mordazas de poliuretano termoplástico con sensores resistivos para manipular objetos frágiles sin riesgo de daño estructural, complementándolo con la optimización kinodinámica de trayectorias mediante MoveIt2 para minimizar los esfuerzos inerciales en las uniones mecánicas y reducir el consumo energético global del manipulador.

# Anexos

## Anexo A. Componentes

Componente | Cantidad | Datasheet | Plano
Raspberry PI4B | 1 | Raspberry PI4B (Datasheet) RP-008341-DS-1-raspberry-pi-4-datasheet.pdf (https://drive.google.com/file/d/1qmCdFdJmNpAvPBalVsW46Ngzcc-sdkqx/view?usp=drive_link) | Raspberry PI4B (Plano)
ESP32 - 30PINES USB-C | 1 | ESP32 - 30 PINES USB-C (Datasheet) esp32_datasheet_en.pd f (https://drive.google.com/file/d/1oXvYgTNdpzASIGf0C9PnYMvHEcnlAUCt/view?usp=drive_link) | ESP32 - 30 PINES USB-C (Plano)
DRIVER A4988 | 2 | DRIVER A4988 (Datasheet) A4988.pdf (https://drive.google.com/file/d/1w8XpWLzDQ-E1gu9JP-IKPH6Sepgqsufn/view?usp=drive_link) | DRIVER A4988 (Plano)
HW-064 XL4015 Conversor DC-DC Step Down de 5A | 2 | HW-064 XL4015 (Datasheet) XL4015_datasheet.pdf (https://drive.google.com/file/d/1RaI9679qtGkyWgeGAawvmk23vhkpeEm5/view?usp=drive_link) xl4015-5a-dc-dc-step-down-adjustable-power-supply-buck-module-led-with-heatsink.pdf (https://drive.google.com/file/d/1E8-zV5BuzyMMkmvZzZf7jEXiUMkPndMC/view?usp=drive_link) | HW-064 XL4015 (Plano)
Tornillos M3x12 | 16 | | Tornillos M3 (Plano)
Tornillos M3x20 | 15
Postes de metal 30mm | 8
Postes de metal 20mm | 8
Rodamiento 1906 | 1 | Rodamiento 1906 (Datasheet) TechnicalSheet-222055.pdf (https://drive.google.com/file/d/1PIjNXWnRl2epXxWHUmTX1qVtKYKDjhFP/view?usp=drive_link) | Rodamiento 1906 (Plano)
Rodamiento mr73 | 2 | S1348b09b741a44f79cf 7ef88ac5f61752.pdf (https://drive.google.com/file/d/1xvqWJtG4nNLxvvK3kc6J5DVcjcFfPe0R/view?usp=drive_link) | Rodamiento MR73 (Plano)
Servo Hiwonder HTS-35H | 3 | Servo Hiwonder HTS-35H (Datasheet) | Servo Hiwonder HTS-35H (Plano)
Ventilador dual para Raspberry | 1 | | Ventilador dual para Raspberry (Plano)
Fuente de poder | 1 | Fuente de Poder (Datasheet)

## Raspberry PI4B (Datasheet)

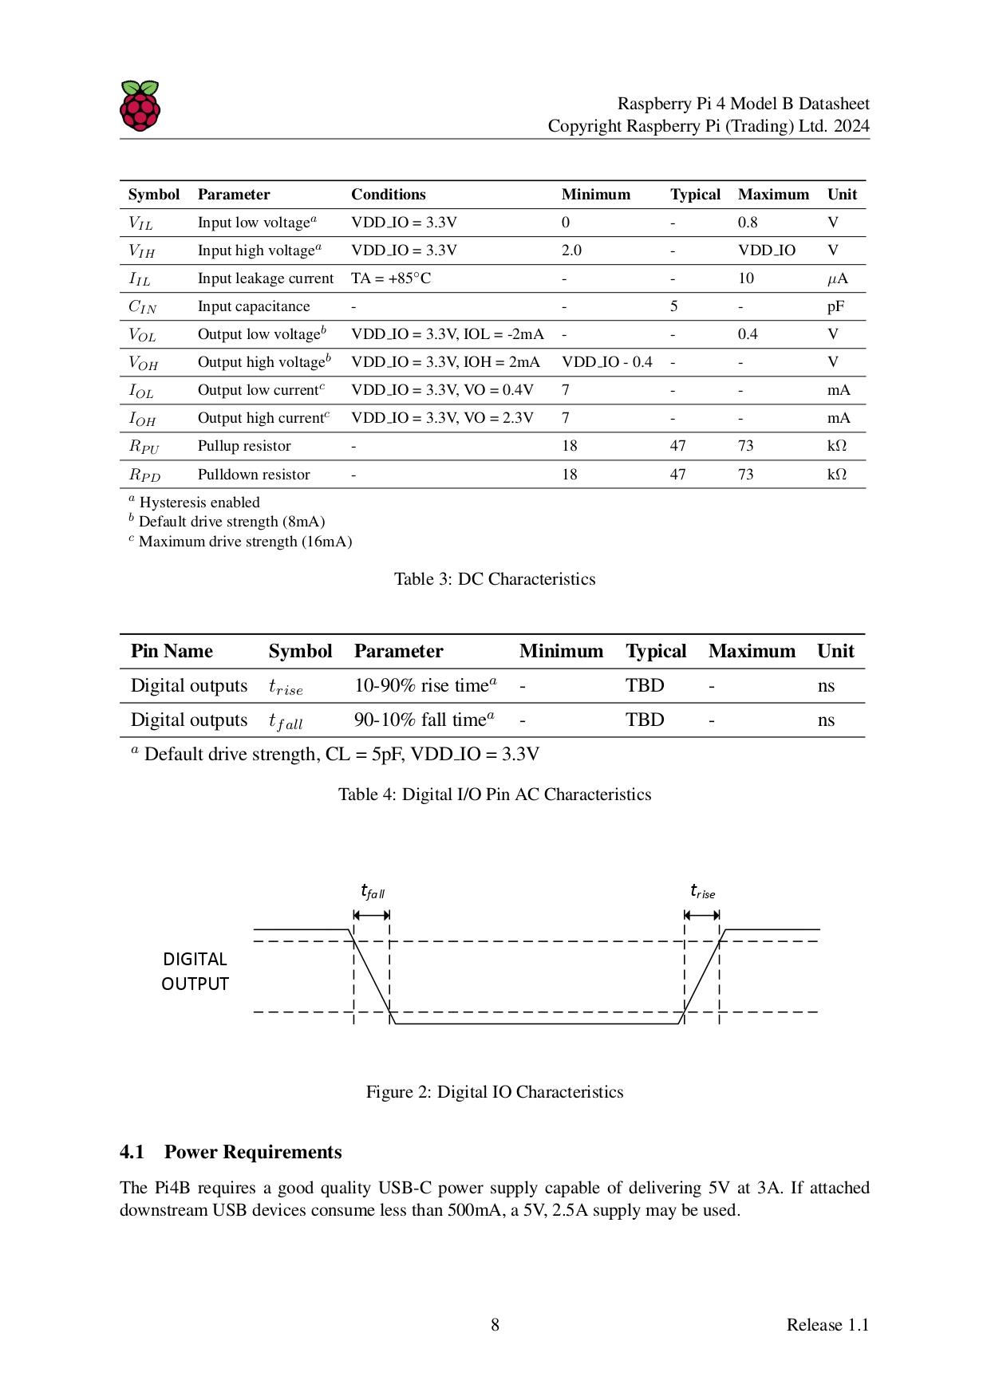
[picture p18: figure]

## Raspberry PI4B (Plano)

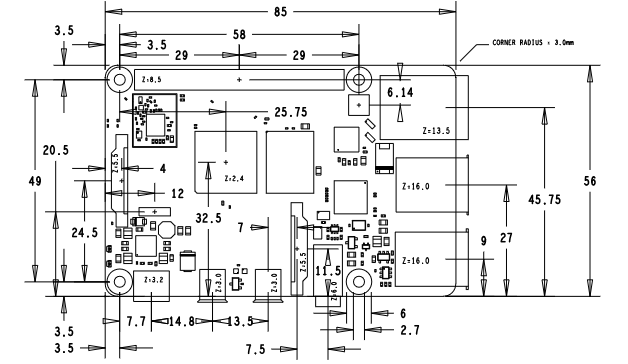
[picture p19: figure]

### ESP32 - 30 PINES USB-C (Datasheet)

### ESP32 - 30 PINES USB-C (Plano)

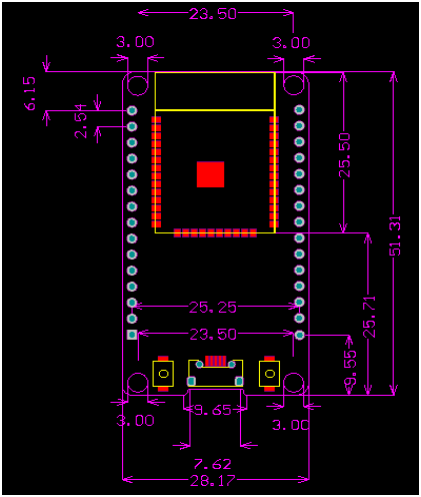
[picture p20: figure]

## DRIVER A4988 (Datasheet)

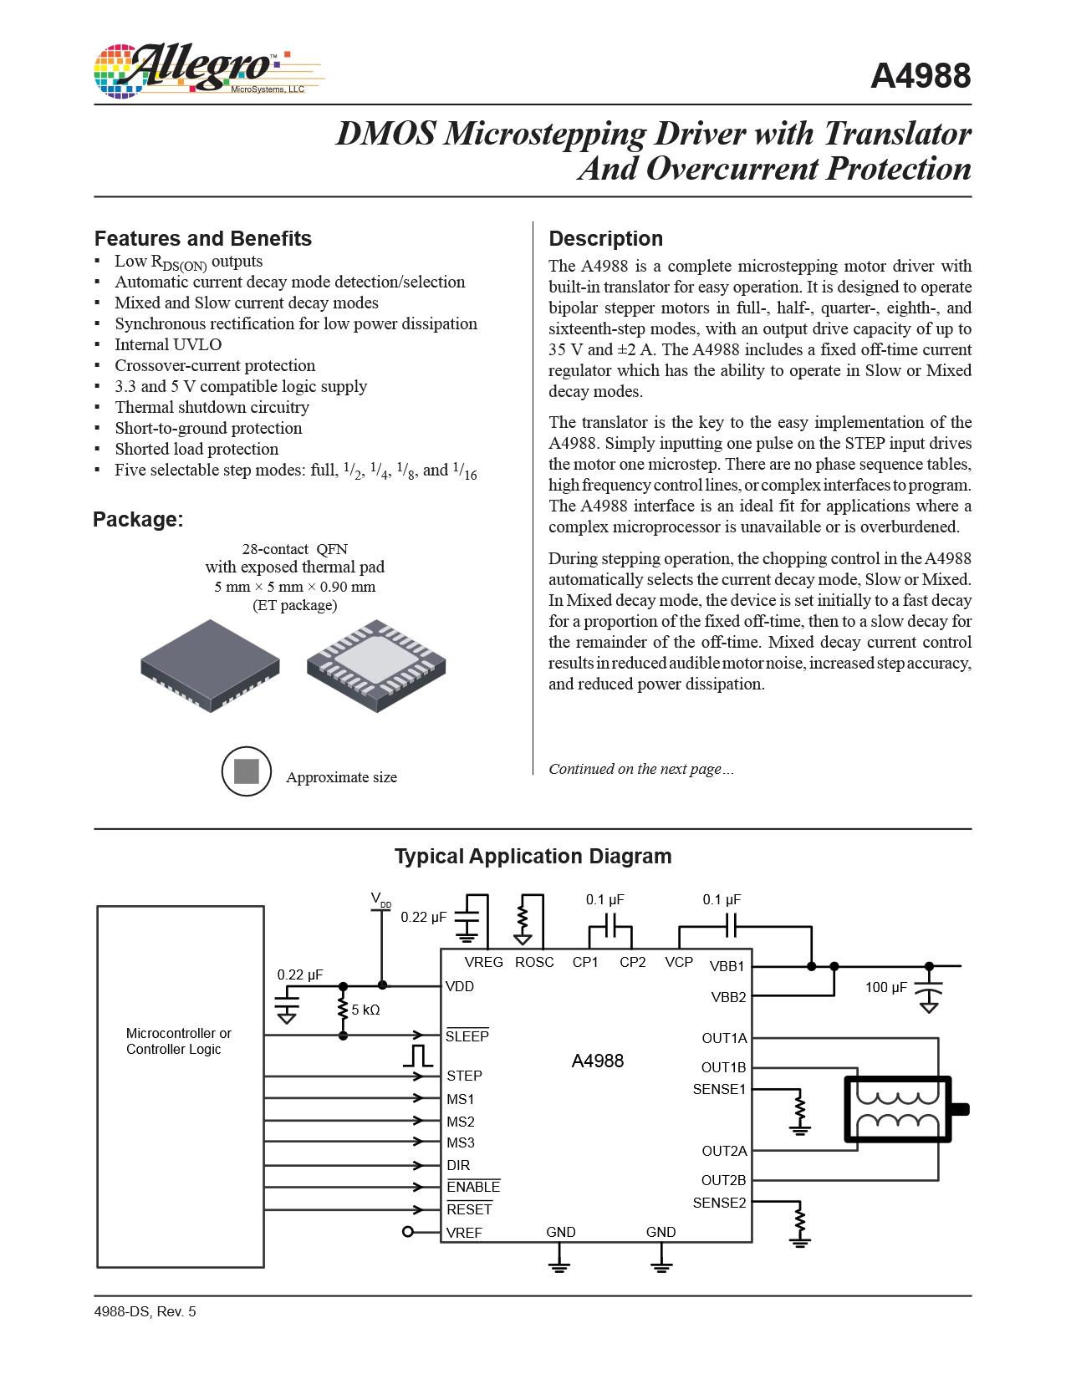
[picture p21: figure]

## DRIVER A4988 (Plano)

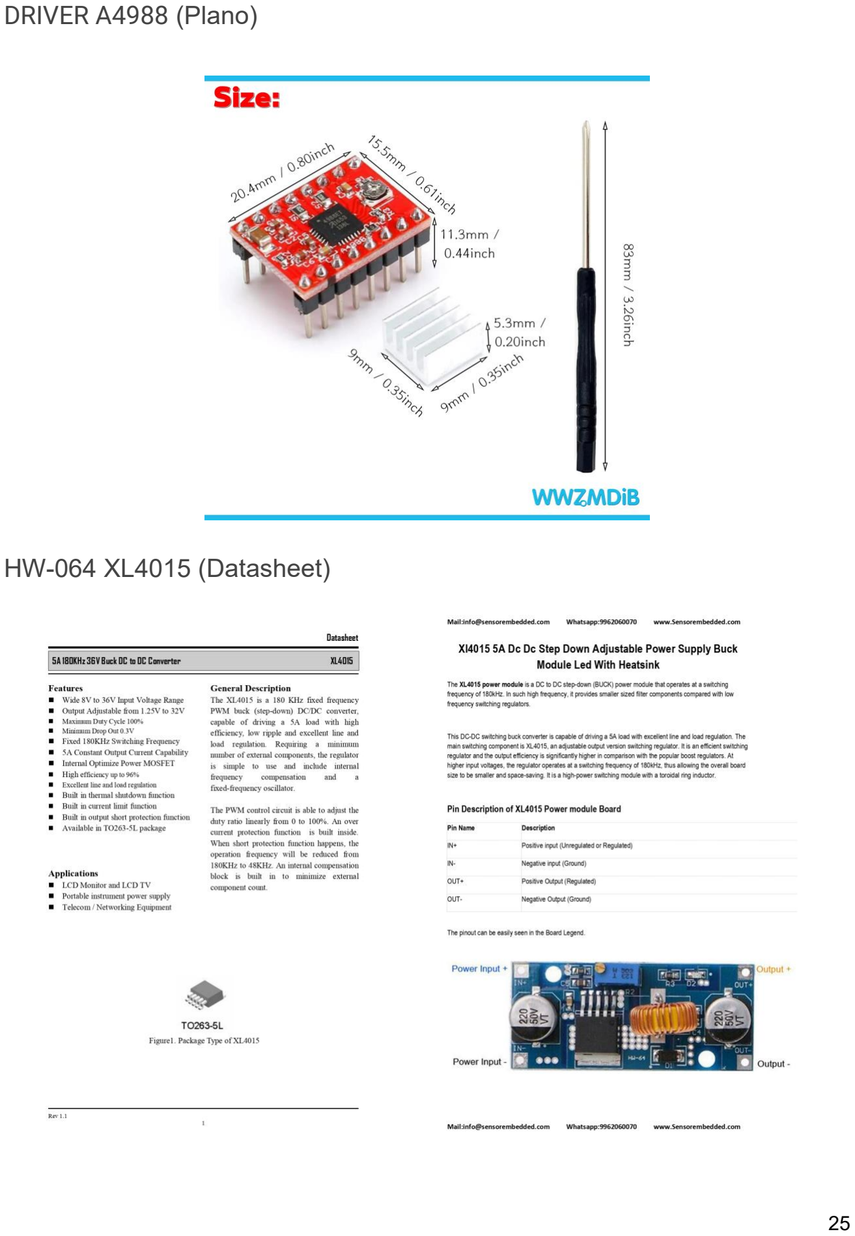
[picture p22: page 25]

### HW-064 XL4015 (Datasheet)

### HW-064 XL4015 (Plano)

### Tornillos M3 (Plano)

## Rodamiento 1906 (Datasheet)

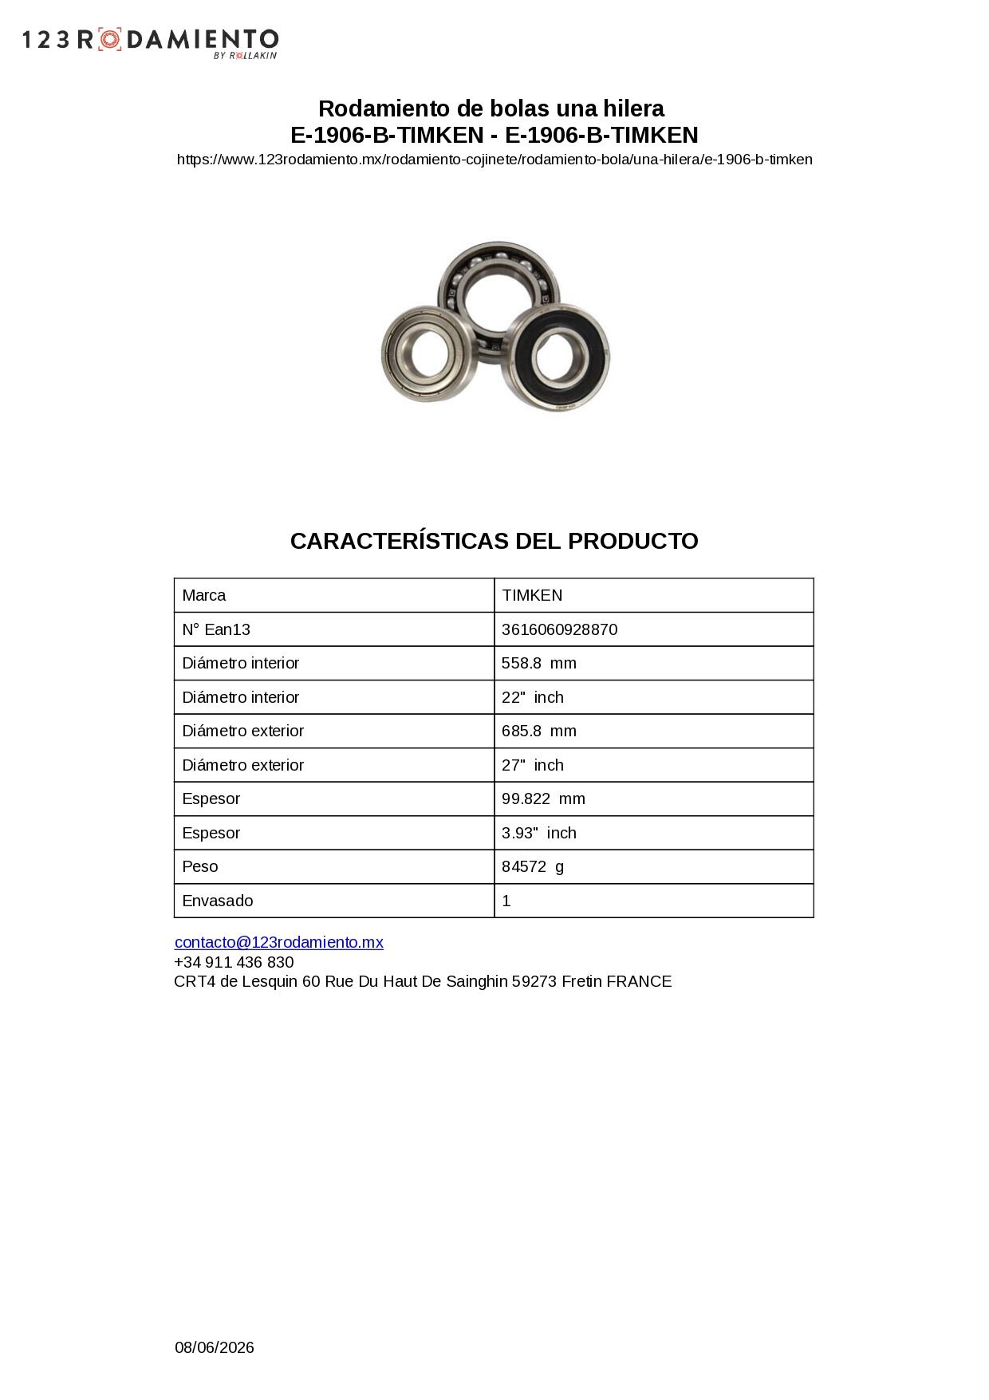
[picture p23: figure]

## Rodamiento 1906 (Plano)

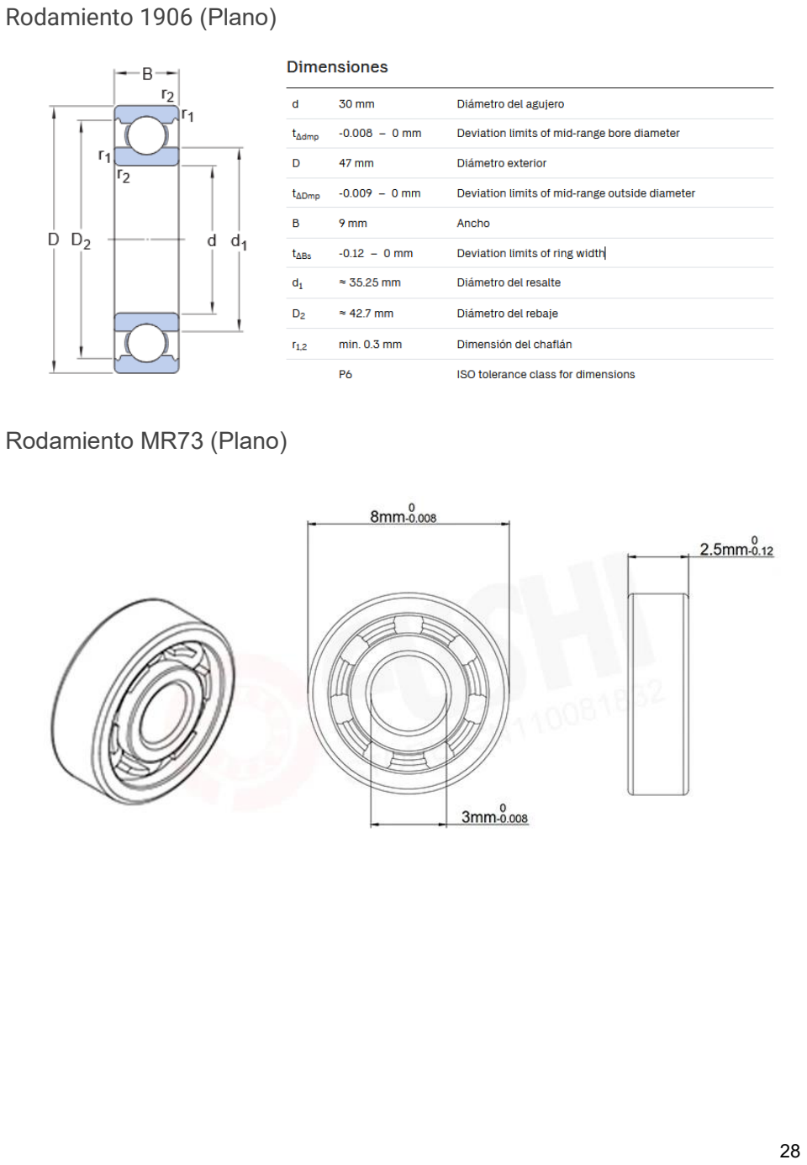
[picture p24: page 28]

### Rodamiento MR73 (Plano)

## Servo Hiwonder HTS-35H (Datasheet)

## Servo Hiwonder HTS-35H (Plano)

## Ventilador dual para Raspberry (Plano)

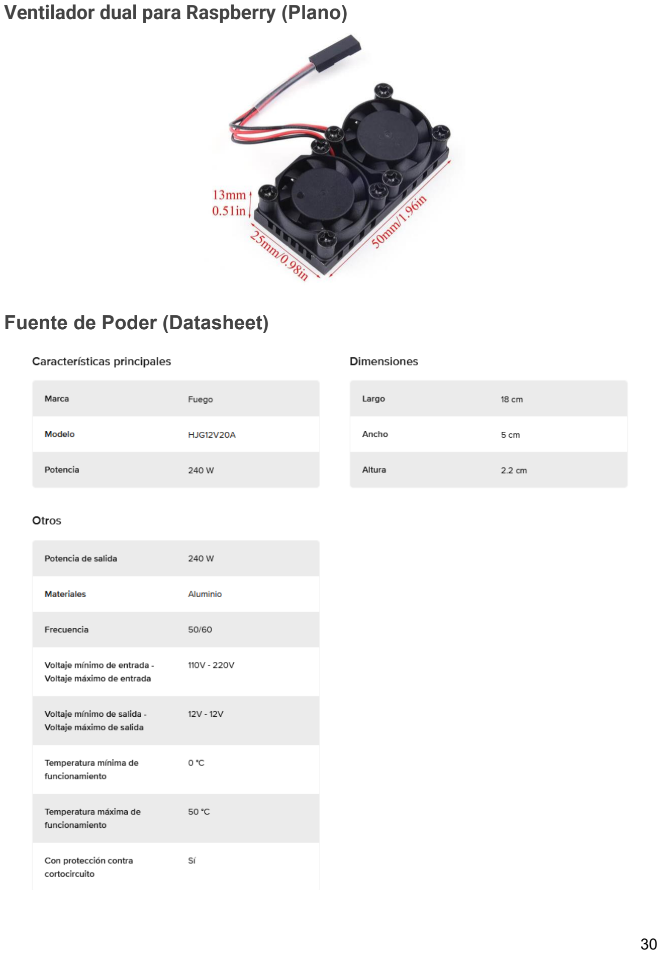
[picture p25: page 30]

### Fuente de Poder (Datasheet)

## Anexo B. Piezas

Pieza | Plano
Base soporte | Base soporte
Base soporte_Superior | Base soporte_Superior
Engrane68 | Engrane68
Engrane68_Conexionmecanismo | Engrane68_Conexionmecanismo
Gripper | Ensamblaje3_Pruebadereduccion_FINAL_PR UEBA
Eslabon2 | Eslabon2
Eslabon2_Prueba3 | Eslabon2_Prueba3
Eslabon4 | Eslabon4
Piñon_68 | Engrane68
Rodamiento 7 - 3 x 3 mm | Rodamiento 7 - 3 x 3 mm
Separador laton H-H M3x20mm | Separador laton H-H M3x20mm
Servo motor | Servo motor
Tornillo M3x16 Plano | Tornillo M3x16 Plano
Tornillo M3x20 Plano | Tornillo M3x20 Plano
Tornillo M3x25 Plano | Tornillo M3x25 Plano
TornilloM3x10_Cruz | TornilloM3x10_Cruz
TuercaM3 | TuercaM3

Eslabón superior | Brazo_gripper
Plataforma | Rotacion_brazo
Base | Disco_soportes
Eslabón inferior | Brazo_base

### Ensamblaje3_Pruebadereduccion_FINAL_PRUEBA

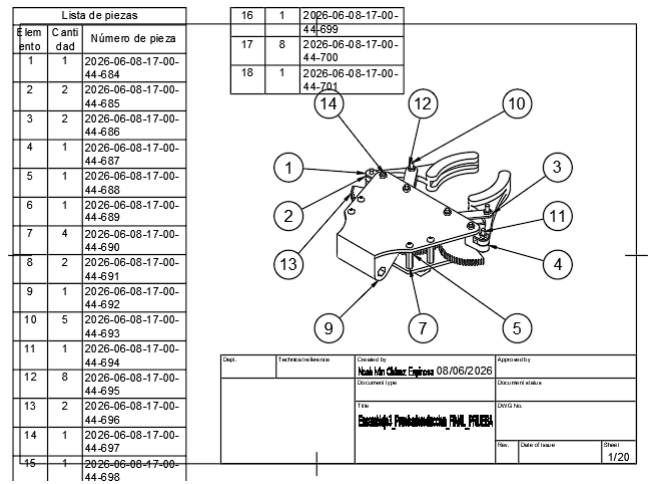
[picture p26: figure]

### Eslabon2_Prueba3

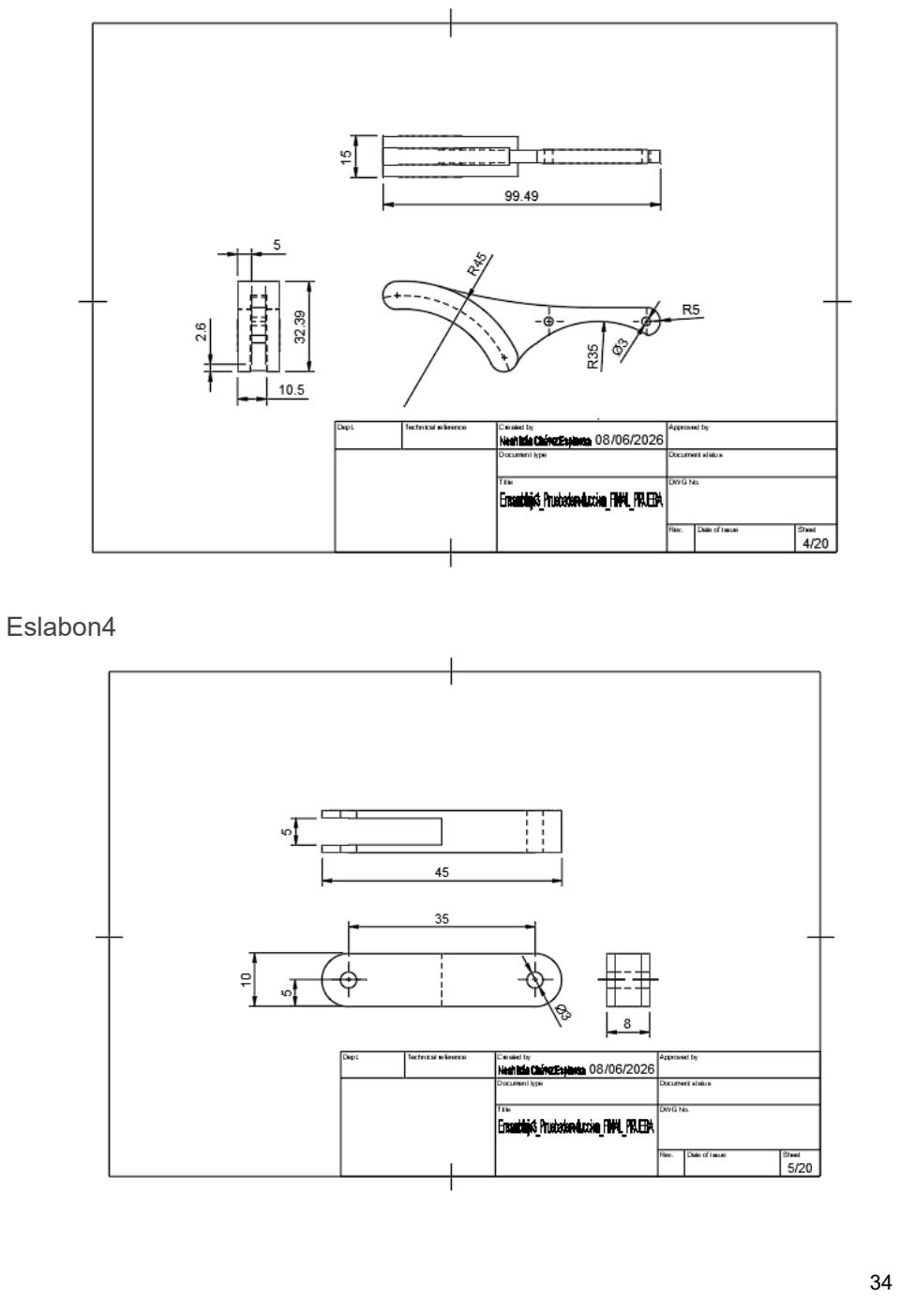
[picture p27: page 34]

### Eslabon4

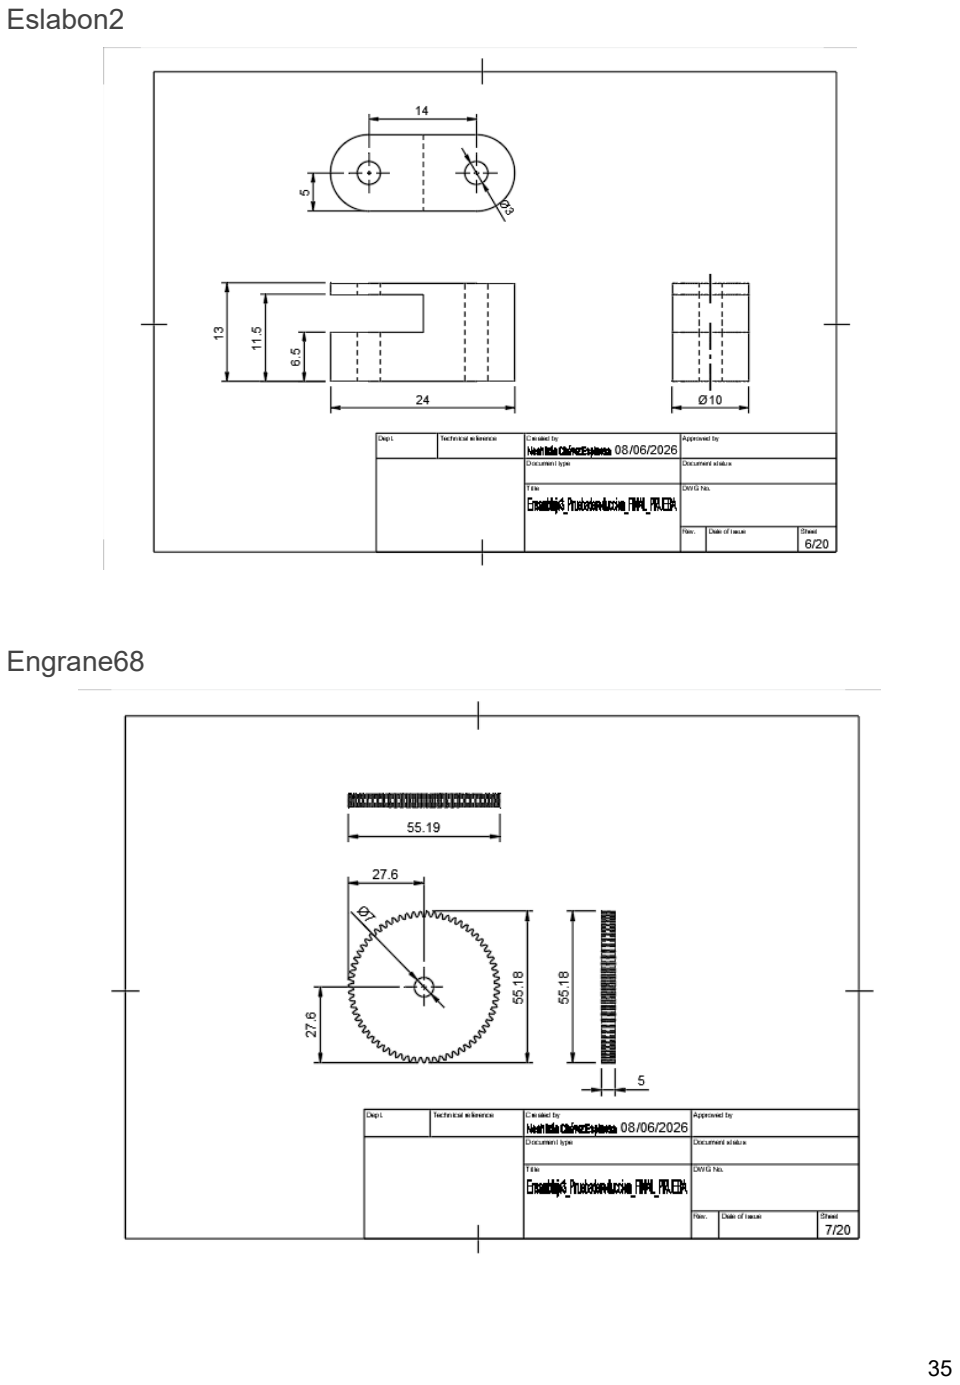
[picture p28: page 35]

### Eslabon2

### Engrane68

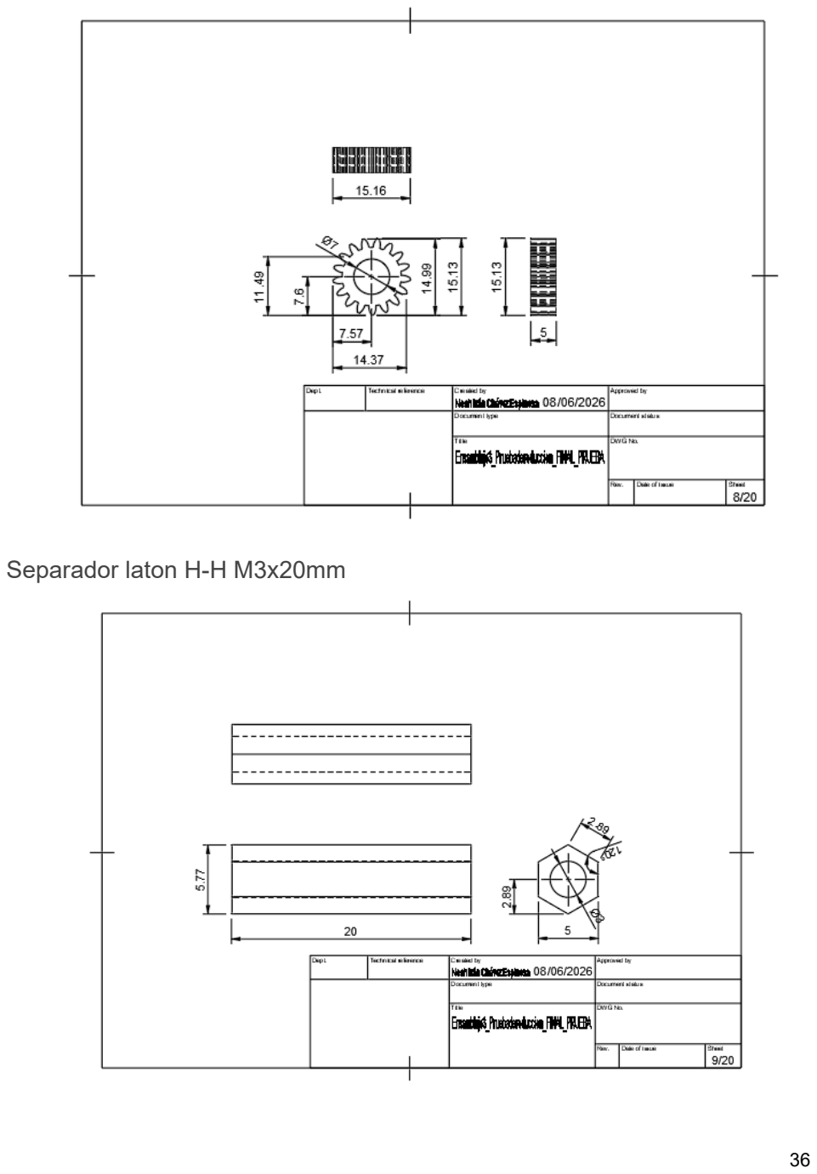
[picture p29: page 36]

### Separador laton H-H M3x20mm

### Rodamiento 7 - 3 x 3 mm

### Base soporte

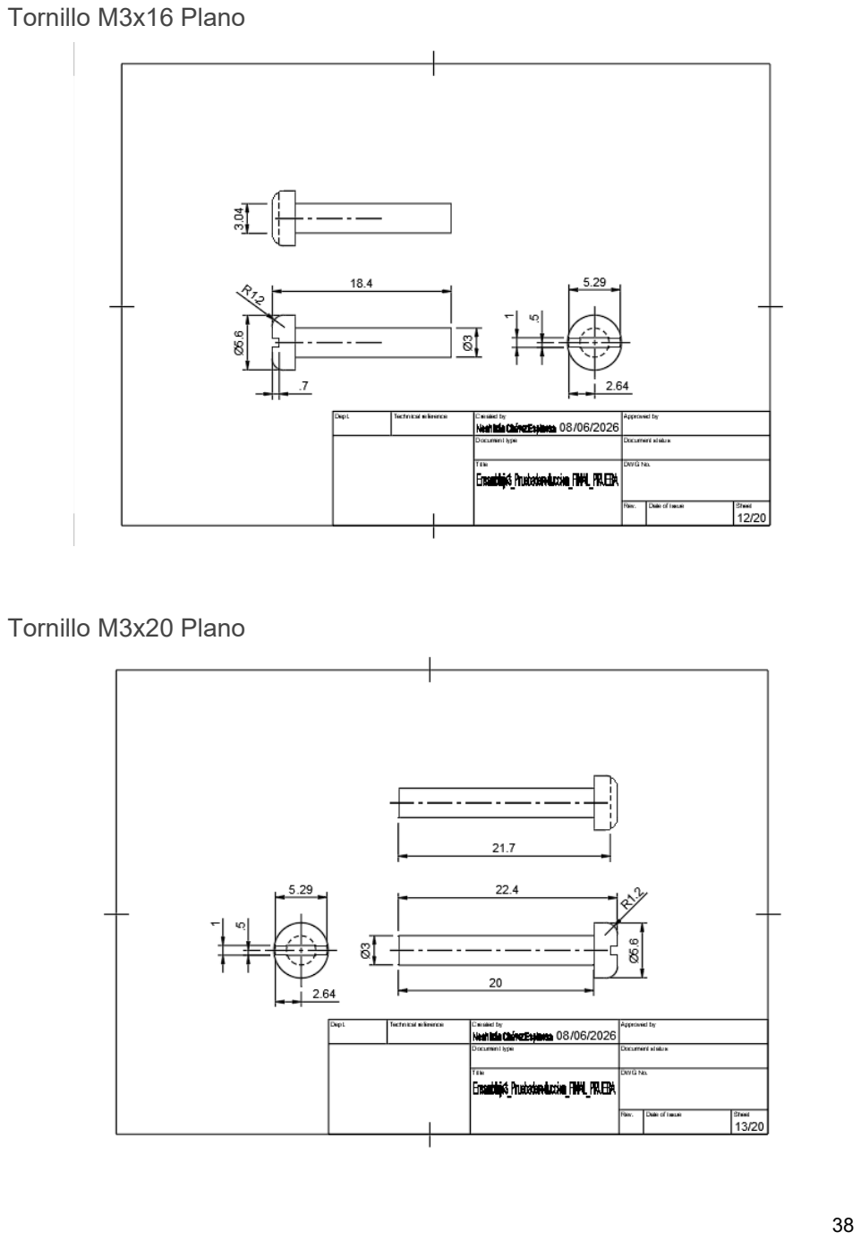
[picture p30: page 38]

### Tornillo M3x16 Plano

### Tornillo M3x20 Plano

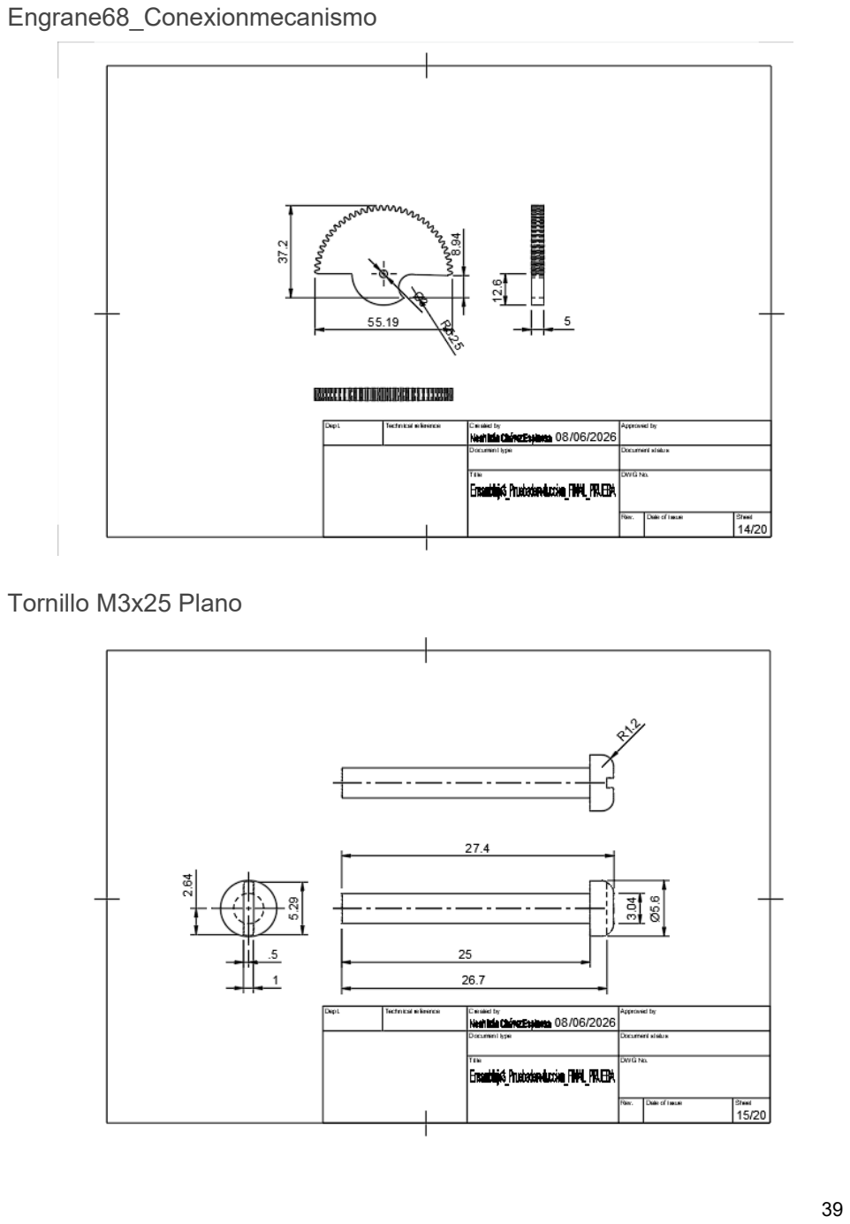
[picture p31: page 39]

### Engrane68_Conexionmecanismo

### Tornillo M3x25 Plano

### Base soporte_Superior

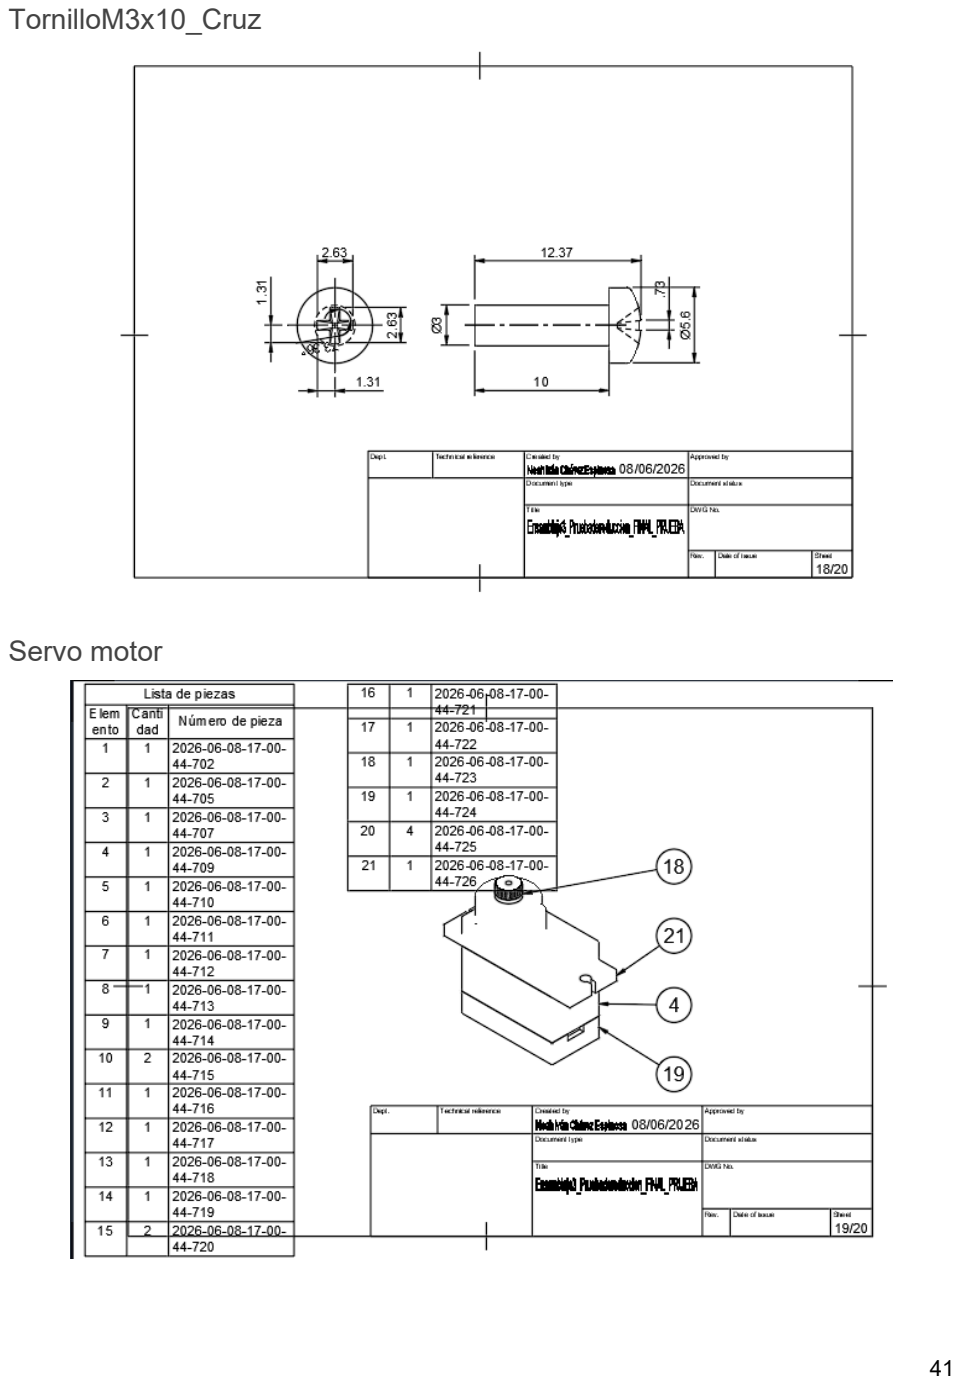
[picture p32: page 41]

### TornilloM3x10_Cruz

### Servo motor

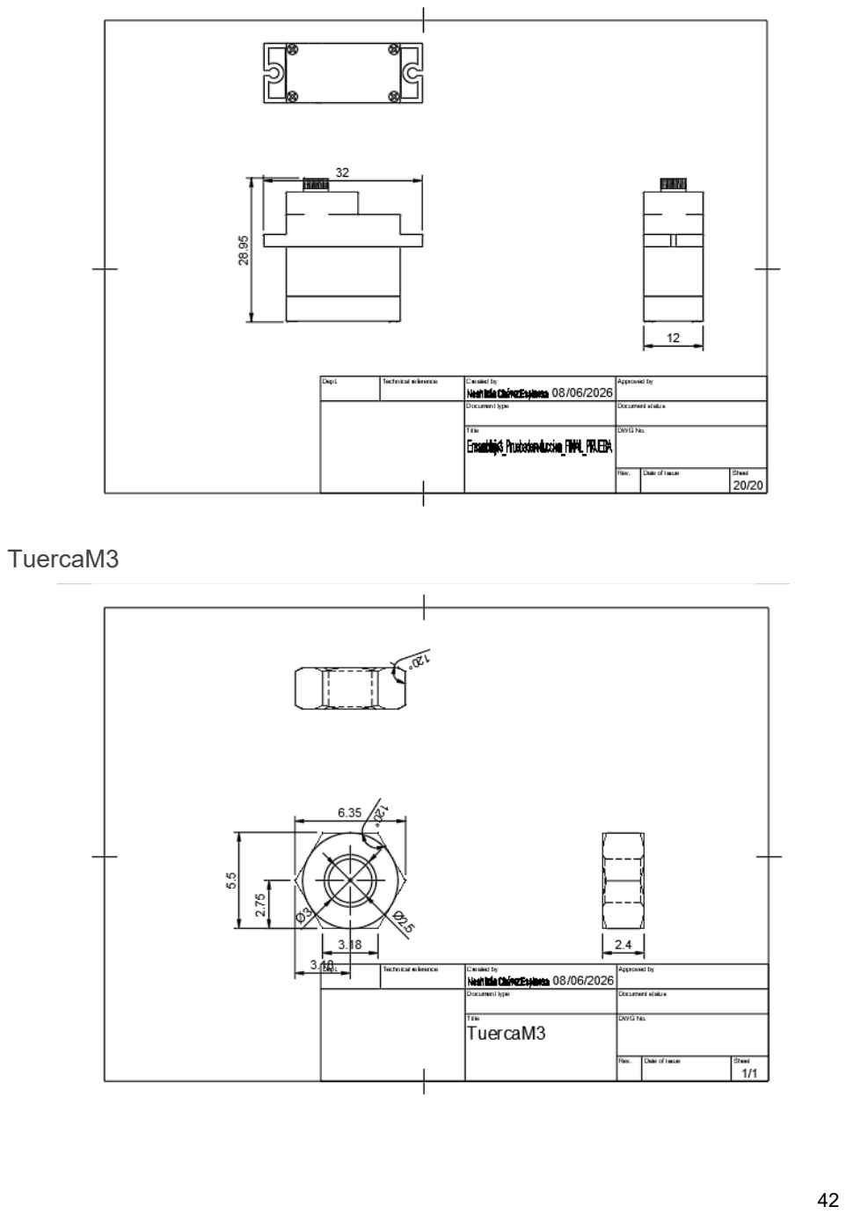
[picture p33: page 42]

### TuercaM3

### Brazo_gripper

### Rotacion_brazo

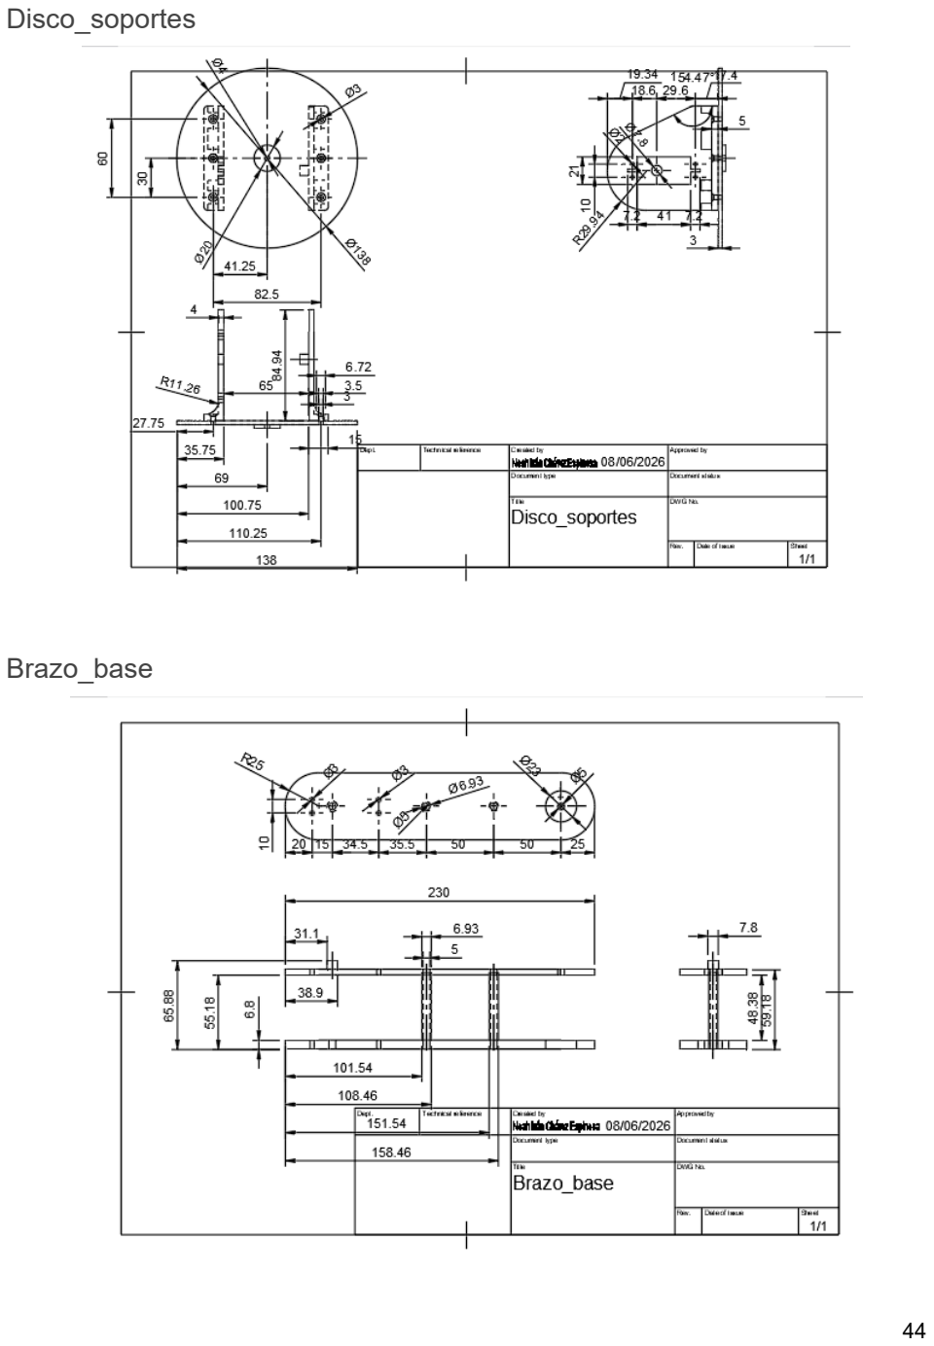
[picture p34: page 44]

### Disco_soportes

### Brazo_base

## Anexo C. Esquemáticos

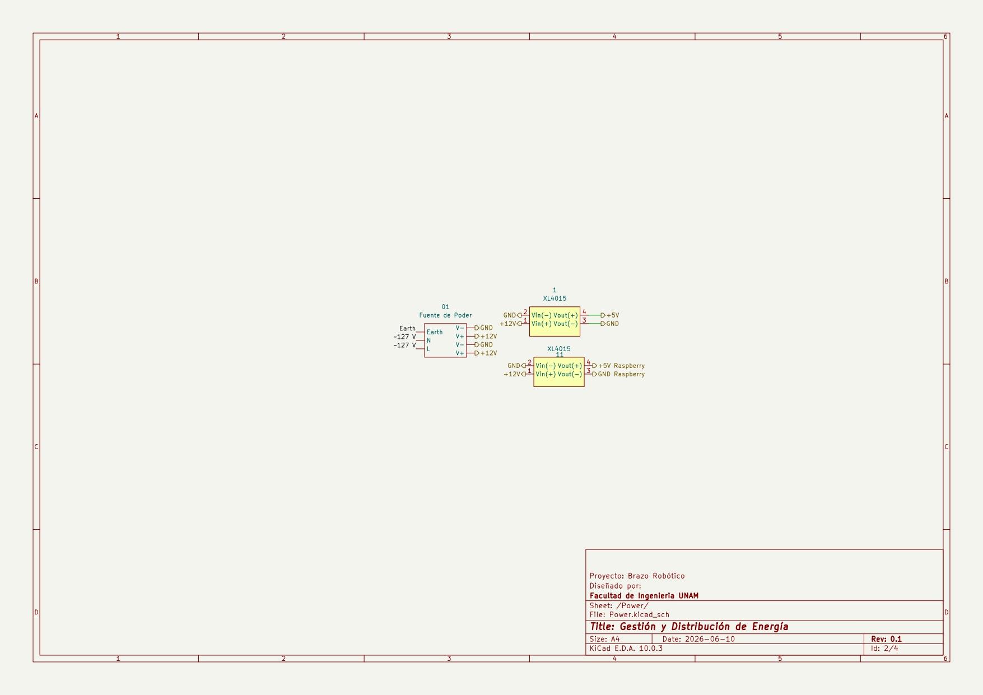
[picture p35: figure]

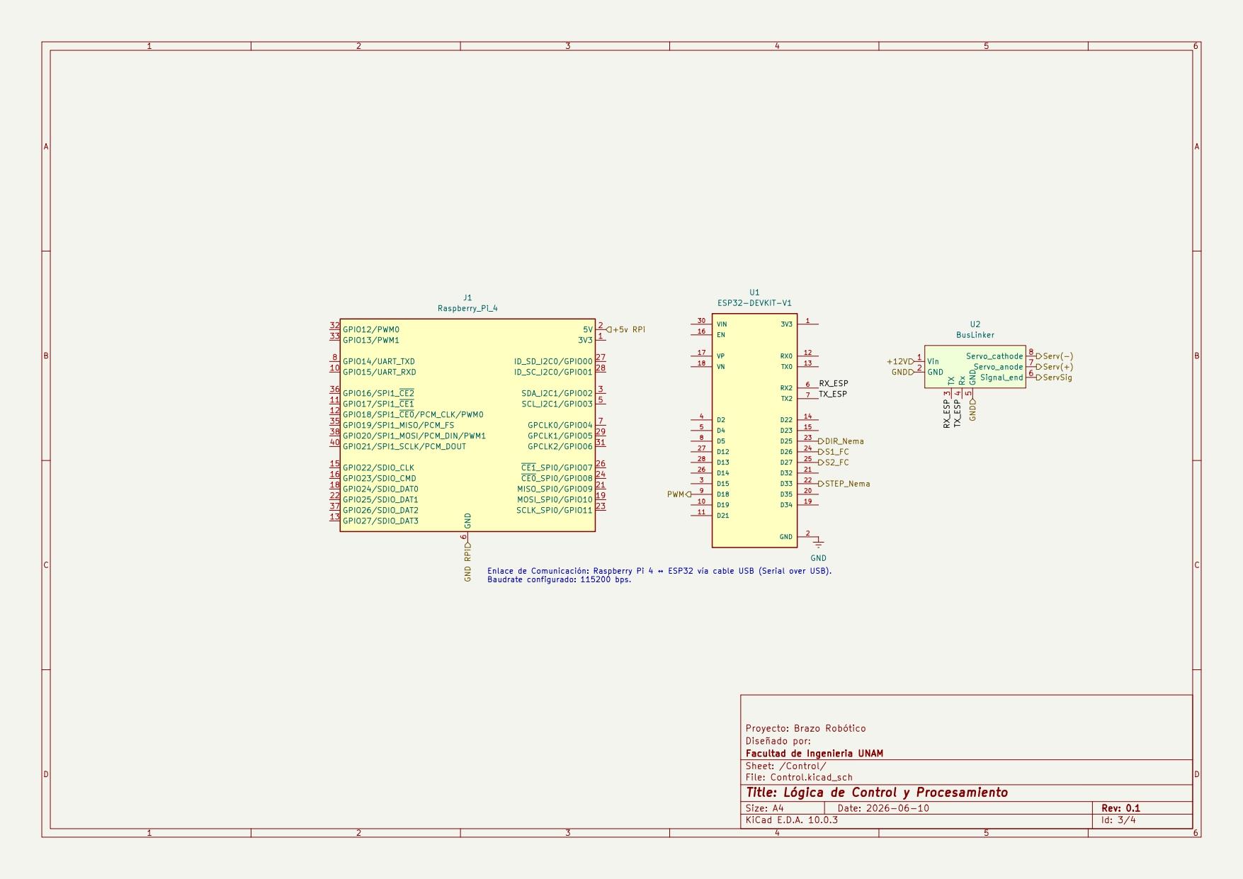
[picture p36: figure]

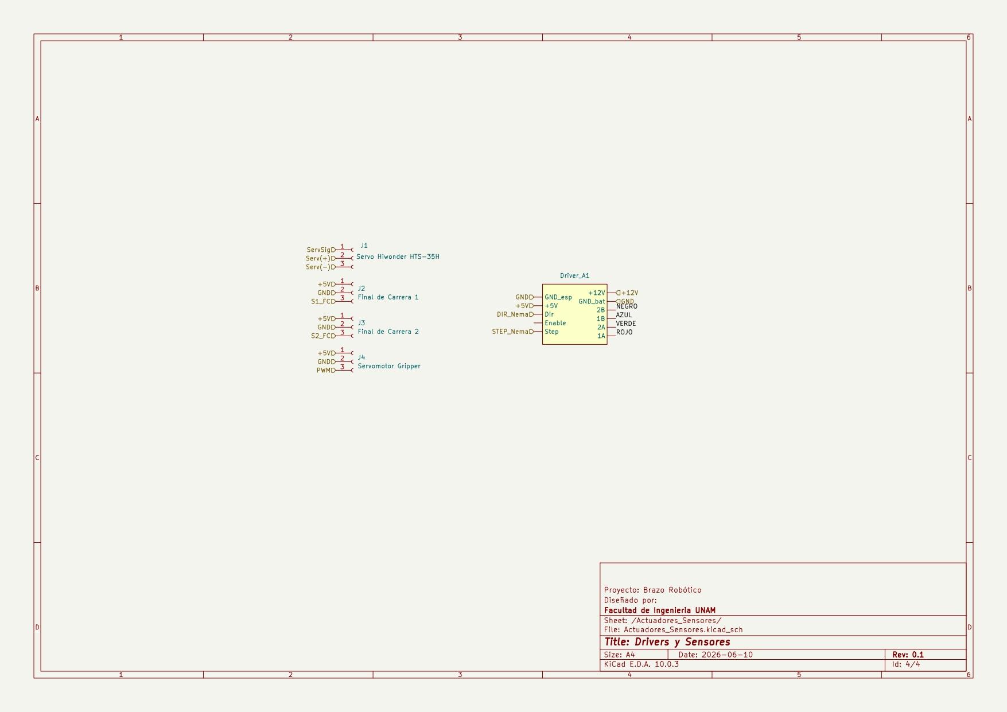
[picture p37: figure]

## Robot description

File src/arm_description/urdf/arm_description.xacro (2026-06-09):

<?xml version="1.0" encoding="utf-8"?>
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
<robot name="Diseño_Final_Brazo_carro_5">

  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
  <link name="world" />

  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
  <joint name="world_to_base" type="fixed">
  <parent link="world" />
  <child link="base_link" />
  <origin xyz="0 0 1.0" rpy="0 0 0" />
  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
  </joint>

  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
  <link name="base_link">
    <inertial>
      <origin xyz="-0.767839023684456 -0.977798899526784 -0.691582390969042" rpy="0 0 0" />
      <mass value="10.4895723696251" />
      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
    </inertial>
    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
  </link>

  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
  <link name="masa_motor_riel_dummy">
    <inertial>
      <mass value="0.064" />
      <origin xyz="0 0 0" rpy="0 0 0" />
      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
    </inertial>
  </link>
  <joint name="masa_motor_riel_joint" type="fixed">
    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
    <origin xyz="-0.895839610962944 -0.977798902169002 -0.64463447777702" rpy="1.5707963267949 0 1.5707963267949" />
    <parent link="base_link" />
    <child link="masa_motor_riel_dummy" />
  </joint>

  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
  <link name="eje_x">
    <inertial>
      <origin xyz="2.30268809181533E-05 -0.00622054699002839 -0.0754124933910654" rpy="0 0 0" />
      <mass value="0.561150750908205" />
      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
    </inertial>
    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
  </link>

  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
  <joint name="moviento_en_x" type="prismatic">
    <origin xyz="-0.895839610962944 -0.977798902169002 -0.64463447777702" rpy="1.5707963267949 0 1.5707963267949" />
    <parent link="base_link" />
    <child link="eje_x" />
    <axis xyz="0 0 1" />
    <limit lower="0" upper="0.30" effort="50" velocity="0.5" />
  </joint>

  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
  <link name="rotacion_brazo">
    <inertial>
      <origin xyz="-2.44249065417534E-15 0.0308605150324593 1.88737914186277E-15" rpy="0 0 0" />
      <mass value="0.105827868458871" />
      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
    </inertial>
    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
  </link>

  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
  <joint name="giro_360" type="fixed">
    <origin xyz="0 0 -0.0700000000000027" rpy="0 0 0" />
    <parent link="eje_x" />
    <child link="rotacion_brazo" />
  </joint>

  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
  <link name="masa_motor_hombro_dummy">
    <inertial>
      <mass value="0.064" />
      <origin xyz="0 0 0" rpy="0 0 0" />
      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
    </inertial>
  </link>
  <joint name="masa_motor_hombro_joint" type="fixed">
    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
    <origin xyz="0 0.0463499999999999 0" rpy="0 1.20138367619357 3.14159265358979" />
    <parent link="rotacion_brazo" />
    <child link="masa_motor_hombro_dummy" />
  </joint>

  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
  <link name="disco_soportes">
    <inertial>
      <origin xyz="-0.000838170732078591 -0.0212543006415097 -0.00166146627505315" rpy="0 0 0" />
      <mass value="0.0982346618732346" />
      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
    </inertial>
    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
  </link>

  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
  <joint name="disco_soportes_rotacion" type="revolute">
    <origin xyz="0 0.0463499999999999 0" rpy="0 1.20138367619357 3.14159265358979" />
    <parent link="rotacion_brazo" />
    <child link="disco_soportes" />
    <axis xyz="0 1 0" />
    <limit lower="-2.094" upper="2.094" effort="3" velocity="6.17" />
  </joint>

  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
  <link name="masa_motor_codo_dummy">
    <inertial>
      <mass value="0.064" />
      <origin xyz="0 0 0" rpy="0 0 0" />
      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
    </inertial>
  </link>
  <joint name="masa_motor_codo_joint" type="fixed">
    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
    <origin xyz="0 -0.0529999999999985 -0.00949999999999551" rpy="-1.5707963267949 1.02839961384078 1.5707963267949" />
    <parent link="disco_soportes" />
    <child link="masa_motor_codo_dummy" />
  </joint>

  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
  <link name="brazo_base">
    <inertial>
      <origin xyz="-1.65889524339491E-11 0.0909111374249095 0.0044382355421646" rpy="0 0 0" />
      <mass value="0.138901841849158" />
      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
    </inertial>
    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
  </link>

  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
  <joint name="brazo_motores" type="revolute">
    <origin xyz="0 -0.0529999999999985 -0.00949999999999551" rpy="-1.5707963267949 1.02839961384078 1.5707963267949" />
    <parent link="disco_soportes" />
    <child link="brazo_base" />
    <axis xyz="0 0 1" />
    <limit lower="-2.094" upper="2.094" effort="3" velocity="6.17" />
  </joint>

  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
  <link name="masa_motor_muneca_dummy">
    <inertial>
      <mass value="0.064" />
      <origin xyz="0 0 0" rpy="0 0 0" />
      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
    </inertial>
  </link>
  <joint name="masa_motor_muneca_joint" type="fixed">
    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
    <origin xyz="0 0.170000000000034 0" rpy="-1.57079632679489 0 1.39726597352321" />
    <parent link="brazo_base" />
    <child link="masa_motor_muneca_dummy" />
  </joint>

  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
  <link name="brazo_gripper">
    <inertial>
      <origin xyz="-1.14352971536391E-14 0.00970468342117248 -0.072570676566811" rpy="0 0 0" />
      <mass value="0.0747618610211338" />
      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
    </inertial>
    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
  </link>

  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
  <joint name="brazo_gripper_azul" type="revolute">
    <origin xyz="0 0.170000000000034 0" rpy="-1.57079632679489 0 1.39726597352321" />
    <parent link="brazo_base" />
    <child link="brazo_gripper" />
    <axis xyz="0 1 0" />
    <limit lower="-2.094" upper="2.094" effort="3" velocity="6.17" />
  </joint>

  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
  <link name="gripper">
    <inertial>
      <origin xyz="0.000333115444986598 0.0381366742086494 0.00835604029932591" rpy="0 0 0" />
      <mass value="0.0316121714248153" />
      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
    </inertial>
    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
  </link>

  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
  <joint name="gripper_mecanismo" type="revolute">
    <origin xyz="-0.00750000000010087 0.000549999999957196 -0.14000000000012" rpy="-1.57079632679488 0 -1.57079632679488" />
    <parent link="brazo_gripper" />
    <child link="gripper" />
    <axis xyz="0 0 1" />
    <limit lower="0.0" upper="6.2831" effort="2" velocity="3.0" />
  </joint>

  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
  <link name="payload_400g">
    <inertial>
      <mass value="0.4" />
      <origin xyz="0 0 0" rpy="0 0 0" />
      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
    </inertial>
    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
  </link>

  <joint name="payload_joint" type="fixed">
    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
    <origin xyz="0 0.1 0" rpy="0 0 0" />
    <parent link="gripper" />
    <child link="payload_400g" />
  </joint>

  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
  <ros2_control name="BrazoCarro" type="system">
    <hardware>
      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
      <plugin>mock_components/GenericSystem</plugin>
      
      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
    </hardware>

    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
    <joint name="moviento_en_x">
      <command_interface name="position" />
      <state_interface name="position" />
      <state_interface name="velocity" />
    </joint>

    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
    <joint name="disco_soportes_rotacion">
      <command_interface name="position" />
      <state_interface name="position" />
      <state_interface name="velocity" />
    </joint>

    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
    <joint name="brazo_motores">
      <command_interface name="position" />
      <state_interface name="position" />
      <state_interface name="velocity" />
    </joint>

    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
    <joint name="brazo_gripper_azul">
      <command_interface name="position" />
      <state_interface name="position" />
      <state_interface name="velocity" />
    </joint>
  
    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
    <joint name="gripper_mecanismo">
      <command_interface name="position" />
      <state_interface name="position" />
      <state_interface name="velocity" />
    </joint>
  </ros2_control>

</robot>

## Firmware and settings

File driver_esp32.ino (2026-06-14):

/*
 * IntegradoMotoresYBase.ino  
 *
 * Correcciones:
 *   1. La tarea FreeRTOS ahora se crea DESPUÉS del homing (elimina race condition).
 *   2. Forward declarations añadidas (necesarias en .cpp; buena práctica en .ino).
 *   3. distanceToGo() leído dentro del mutex.
 *
 * Hardware:
 *   GPIO 16/17 : Servos Hiwonder (serial bus)
 *   GPIO 18    : Gripper SG90 (PWM)
 *   GPIO 25/33 : Motor a pasos A4988 (DIR/STEP)
 *   GPIO 26    : Final de carrera INICIO
 *   GPIO 27    : Final de carrera FIN
 */

#include "LobotSerialServoControl.h"
#include <AccelStepper.h>
#include <ESP32Servo.h>

// ── Forward declarations (bug 2) ──────────────────────────────────
void ejecutarHoming();
void procesarTrama(String payload);
void moverAMilimetros(float milimetros);
int  radToHiwonder(float rad);

// ── Servos Hiwonder ───────────────────────────────────────────────
#define RXD2 16
#define TXD2 17

HardwareSerial SerialPort(2);
LobotSerialServoControl BusServo(SerialPort);

#define ID_HOMBRO 1
#define ID_CODO   2
#define ID_MUNECA 3

const int   MOVE_TIME_MS = 20;
const int   DEADBAND     = 4;
const float LIM_RAD      = 2.0944f;   // ±120°

int lastHombro = -9999;
int lastCodo   = -9999;
int lastMuneca = -9999;

// ── Gripper SG90 ──────────────────────────────────────────────────
#define PIN_GRIPPER 18

Servo servoGripper;
int lastGripperGrados = -999;

// ── Finales de carrera ────────────────────────────────────────────
#define FC_INICIO 26
#define FC_FIN    27

// ── Motor a pasos ─────────────────────────────────────────────────
#define STEP_PIN 33
#define DIR_PIN  25

const float PASOS_POR_MM = 25.0f;

AccelStepper stepper(AccelStepper::DRIVER, STEP_PIN, DIR_PIN);
SemaphoreHandle_t stepperMutex;

long recorridoMaxPasos = 0;

// ── Buffer serial ─────────────────────────────────────────────────
String buffer = "";
bool   leyendo = false;

// Contador de tramas a descartar tras el homing.
// El serial_bridge manda 50 tramas/seg; descartamos las primeras 3 segundos
// (150 tramas) para que ROS termine de procesar la trayectoria de calibración
// y los valores residuales de 0.46m no lleguen al motor.
int tramasFlushPendientes = 150;

// ════════════════════════════════════════════════════════════════════
// TAREA FREERTOS — core 0
// Se crea DESPUÉS del homing → nunca compite con ejecutarHoming().
// ════════════════════════════════════════════════════════════════════
void tareaMotorPasos(void* pvParameters) {
  // ── Registrar la tarea en el WDT del core 0 ──────────────────────
  esp_task_wdt_add(NULL);

  for (;;) {
    bool idle = false;
    if (xSemaphoreTake(stepperMutex, portMAX_DELAY) == pdTRUE) {
      stepper.run();
      idle = (stepper.distanceToGo() == 0);
      xSemaphoreGive(stepperMutex);
    }

    // ── Alimenta el WDT en cada ciclo, no solo cuando idle ──────────
    esp_task_wdt_reset();

    if (idle) {
      vTaskDelay(1);  // cede CPU al scheduler cuando no hay movimiento
    }
    // Si hay movimiento activo, no cedemos CPU para máxima resolución de pasos
  }
}

// ════════════════════════════════════════════════════════════════════
// HOMING — bloquea setup(); la tarea FreeRTOS aún NO existe aquí.
// ════════════════════════════════════════════════════════════════════
void ejecutarHoming() {
  Serial.println("HOMING: Iniciando secuencia de calibración...");

  // Fase 1: avanzar hasta FC_FIN
  Serial.println("HOMING: Buscando tope final (FC_FIN)...");
  stepper.setSpeed(300);
  while (digitalRead(FC_FIN) == HIGH) {
    stepper.runSpeed();
    while (Serial.available() > 0) Serial.read();   // descartar tramas de ROS
  }

  stepper.stop();
  recorridoMaxPasos = stepper.currentPosition();
  Serial.print("HOMING: FC_FIN. Recorrido real: ");
  Serial.print(recorridoMaxPasos / PASOS_POR_MM, 1);
  Serial.println(" mm");

  // Retroceso 3 mm para soltar el sensor
  stepper.setMaxSpeed(600); stepper.setAcceleration(300);
  stepper.moveTo(recorridoMaxPasos - round(3.0f * PASOS_POR_MM));
  while (stepper.distanceToGo() != 0) {
    stepper.run();
    while (Serial.available() > 0) Serial.read();
  }
  delay(300);

  // Fase 2: regresar hasta FC_INICIO
  Serial.println("HOMING: Regresando al origen (FC_INICIO)...");
  stepper.setSpeed(-300);
  while (digitalRead(FC_INICIO) == HIGH) {
    stepper.runSpeed();
    while (Serial.available() > 0) Serial.read();
  }

  stepper.stop();
  stepper.setCurrentPosition(0);
  Serial.println("HOMING: FC_INICIO. Posicion 0 establecida.");

  // Avance 2 mm para soltar el sensor y redefinir el cero despegado
  stepper.setMaxSpeed(600); stepper.setAcceleration(300);
  stepper.moveTo(round(2.0f * PASOS_POR_MM));
  while (stepper.distanceToGo() != 0) {
    stepper.run();
    while (Serial.available() > 0) Serial.read();
  }
  stepper.setCurrentPosition(0);

  // ── Test gripper post-homing ──────────────────────────────────────
  // Manda el servo a 0° para verificar que el SG90 responde
  servoGripper.write(0);
  delay(1000);
  // Luego a 110° (abierto total)
  servoGripper.write(110);
  delay(1000);
  // Regresa a 0° y se queda ahí
  servoGripper.write(0);
  delay(500);

  // Handshake con la Raspberry Pi
  Serial.println("CALIBRADO");
  //Serial.print("HOMING: Completo. Recorrido util: ");
  //Serial.print(recorridoMaxPasos / PASOS_POR_MM, 1);
  //Serial.println(" mm. Sistema listo.");
}

// ════════════════════════════════════════════════════════════════════
// SETUP
// ════════════════════════════════════════════════════════════════════
void setup() {
  Serial.begin(115200, SERIAL_8N1);
  SerialPort.begin(115200, SERIAL_8N1, RXD2, TXD2);

  pinMode(FC_INICIO, INPUT_PULLUP);
  pinMode(FC_FIN,    INPUT_PULLUP);

  servoGripper.setPeriodHertz(50);
  servoGripper.attach(PIN_GRIPPER, 500, 2400);

  stepper.setMaxSpeed(600);
  stepper.setAcceleration(300);

  stepperMutex = xSemaphoreCreateMutex();

  delay(1000);
  Serial.println("ESP32 ONLINE - Iniciando homing automatico...");

  // ── Homing primero, tarea después (bug 1 corregido) ──────────────
  ejecutarHoming();

  // La tarea solo se crea cuando el homing ya terminó.
  // A partir de aquí, TODO acceso al stepper debe pasar por el mutex.
  xTaskCreatePinnedToCore(tareaMotorPasos, "MotorPasos",
                          2048, NULL, 2, NULL, 0);
}

// ════════════════════════════════════════════════════════════════════
// LOOP — core 1
// ════════════════════════════════════════════════════════════════════

// Añade estas variables globales junto a las otras:
// String buffer = "";
// bool   leyendo = false;
unsigned long tiempoInicioTrama = 0;  // ← AÑADIR GLOBAL
const unsigned long TRAMA_TIMEOUT_MS = 50; // ← AÑADIR GLOBAL

void loop() {
  // Timeout: si llevamos >50ms construyendo una trama sin cerrarla,
  // algo se corrompió — descartamos y esperamos la siguiente.
  if (leyendo && (millis() - tiempoInicioTrama > TRAMA_TIMEOUT_MS)) {
    buffer  = "";
    leyendo = false;
    // No imprimir error aquí para no saturar el serial con el bridge
  }

  while (Serial.available() > 0) {
    char c = Serial.read();

    if (c == '<') {
      // Siempre reinicia al detectar '<', incluso si ya estábamos leyendo
      // (significa que la trama anterior llegó incompleta)
      buffer            = "";
      leyendo           = true;
      tiempoInicioTrama = millis();  // ← marca el inicio

    } else if (c == '>' && leyendo) {
      leyendo = false;

      // Verificación rápida: una trama válida tiene exactamente 4 comas
      int nComas = 0;
      for (int i = 0; i < (int)buffer.length(); i++) {
        if (buffer[i] == ',') nComas++;
      }

      if (nComas == 4) {
        procesarTrama(buffer);
      }
      // Si no tiene 4 comas, la trama llegó fragmentada — silenciosamente descartamos
      buffer = "";

    } else if (leyendo) {
      buffer += c;
      if (buffer.length() > 80) {  // overflow guard
        buffer  = "";
        leyendo = false;
      }
    }
    // Caracteres fuera de trama (\n, \r, ruido) se ignoran implícitamente
  }
}

// ════════════════════════════════════════════════════════════════════
// PROCESAR TRAMA <riel_m, hombro_rad, codo_rad, muneca_rad, gripper_norm>
// ════════════════════════════════════════════════════════════════════
void procesarTrama(String payload) {
  float valores[5];
  int   index = 0;

  // ── FIX: usar sscanf en lugar del parser manual con indexOf/substring.
  // El parser original podía dejar index < 5 si la trama traía espacios,
  // \r, o si el último campo no terminaba en coma — causando ERR:FALTAN_VALORES.
  int leidos = sscanf(payload.c_str(), "%f,%f,%f,%f,%f",
                      &valores[0], &valores[1], &valores[2],
                      &valores[3], &valores[4]);

  if (leidos != 5) {
    Serial.print("ERR:FALTAN_VALORES:"); Serial.println(leidos);
    return;
  }

  // Motor a pasos — acceso protegido por mutex
  float rielMM     = valores[0] * 1000.0f;

  // Descartar tramas residuales post-homing mientras ROS se asienta
  if (tramasFlushPendientes > 0) {
    tramasFlushPendientes--;
    if (tramasFlushPendientes == 0) {
      Serial.println("INFO: Flush post-homing completo.");
    }
    return;
  }

  long  pasosNuevo = round(rielMM * PASOS_POR_MM);
  if (xSemaphoreTake(stepperMutex, portMAX_DELAY) == pdTRUE) {
    if (pasosNuevo != stepper.targetPosition()) {
      moverAMilimetros(rielMM);
    }
    xSemaphoreGive(stepperMutex);
  }

  // Servos Hiwonder
  int posHombro = radToHiwonder(valores[1]);
  int posCodo   = radToHiwonder(valores[2]);
  int posMuneca = radToHiwonder(valores[3]);

  if (abs(posHombro - lastHombro) > DEADBAND) {
    BusServo.LobotSerialServoMove(ID_HOMBRO, posHombro, MOVE_TIME_MS);
    lastHombro = posHombro;
  }
  if (abs(posCodo - lastCodo) > DEADBAND) {
    BusServo.LobotSerialServoMove(ID_CODO, posCodo, MOVE_TIME_MS);
    lastCodo = posCodo;
  }
  if (abs(posMuneca - lastMuneca) > DEADBAND) {
    BusServo.LobotSerialServoMove(ID_MUNECA, posMuneca, MOVE_TIME_MS);
    lastMuneca = posMuneca;
  }

  // Gripper SG90
  // valores[4] viene en escala [0.0, 1.0] desde la GUI. 
  // Multiplicamos por 110 para que 1 = 110 grados y 0 = 0 grados.
  int grados = constrain((int)round(valores[4] * 110.0f), 0, 180);
  
  if (abs(grados - lastGripperGrados) >= 1) {
    servoGripper.write(grados);
    lastGripperGrados = grados;
  }
}

// ════════════════════════════════════════════════════════════════════
// UTILIDADES
// ════════════════════════════════════════════════════════════════════
int radToHiwonder(float rad) {
  return constrain(500 + (int)(rad * 500.0f / LIM_RAD), 0, 1000);
}

// Llamar solo con el mutex ya tomado
void moverAMilimetros(float milimetros) {
  long pasos = constrain((long)round(milimetros * PASOS_POR_MM), 0L, recorridoMaxPasos);
  stepper.moveTo(pasos);
}

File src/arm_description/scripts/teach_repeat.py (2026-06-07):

#!/usr/bin/env python3
"""
teach_repeat.py  (v3)
=====================
Control individual de actuadores Hiwonder via ESP32.

Flujo por motor:
  Selección → Ingreso de pose (rad o grados) → Vista previa de trama ESP32
  → Envío al controlador → Barra de progreso (bloqueante)
  → Confirmación de éxito / timeout → Menú de nuevo

Incluye además: grabar/reproducir trayectorias completas y E-STOP.
"""

import math, time, threading, sys

import rclpy
from rclpy.node import Node
from sensor_msgs.msg import JointState
from std_msgs.msg import String
from trajectory_msgs.msg import JointTrajectory, JointTrajectoryPoint

# ══════════════════════════════════════════════════════════════════
# DEFINICIÓN DE JOINTS
# (id, etiqueta, joint_name, min, max, unidad, tolerancia_convergencia)
# ══════════════════════════════════════════════════════════════════
JOINT_DEFS = [
    (1, 'Riel   ', 'moviento_en_x',            0.000,  0.300, 'm  ', 0.005),
    (2, 'Hombro ', 'disco_soportes_rotacion',  -2.094,  2.094, 'rad', 0.050),
    (3, 'Codo   ', 'brazo_motores',            -2.094,  2.094, 'rad', 0.050),
    (4, 'Muñeca ', 'brazo_gripper_azul',       -2.094,  2.094, 'rad', 0.050),
    (5, 'Gripper', 'gripper_mecanismo',          0.000,  1.000, 'rad', 0.050),
]

ARM_JOINTS    = [d[2] for d in JOINT_DEFS[:4]]
GRIPPER_JOINT = JOINT_DEFS[4][2]
ALL_JOINTS    = [d[2] for d in JOINT_DEFS]

ARM_TOPIC      = '/arm_controller/joint_trajectory'
GRIPPER_TOPIC  = '/gripper_controller/joint_trajectory'
FEEDBACK_TOPIC = '/esp32/feedback'

MOVE_TIMEOUT = 12.0   # segundos máximos esperando convergencia
SEP          = '─' * 58


# ══════════════════════════════════════════════════════════════════
# NODO ROS 2
# ══════════════════════════════════════════════════════════════════
class ControlNode(Node):
    def __init__(self):
        super().__init__('teach_repeat_node')
        self.sub = self.create_subscription(
            JointState, '/joint_states', self._state_cb, 10)
        self.feedback_sub = self.create_subscription(
            String, FEEDBACK_TOPIC, self._feedback_cb, 10)
        self.arm_pub     = self.create_publisher(JointTrajectory, ARM_TOPIC,     10)
        self.gripper_pub = self.create_publisher(JointTrajectory, GRIPPER_TOPIC, 10)

        self._pos:     dict = {j: 0.0 for j in ALL_JOINTS}
        self._ready:   bool = False
        self._last_fb: str  = ''
        self.waypoints:list = []   # waypoints solo de ARM_JOINTS

    def _state_cb(self, msg):
        for name, pos in zip(msg.name, msg.position):
            if name in self._pos:
                self._pos[name] = pos
        self._ready = True

    def _feedback_cb(self, msg):
        self._last_fb = msg.data

    @property
    def arm_pos(self):
        return [self._pos[j] for j in ARM_JOINTS]

    @property
    def gripper_pos(self):
        return self._pos[GRIPPER_JOINT]

    def esp32_frame(self, override=None):
        """Construye <V1,V2,V3,V4,V5> con posiciones actuales y override opcional."""
        vals = [(override or {}).get(jn, self._pos[jn]) for jn in ALL_JOINTS]
        return '<' + ','.join(f'{v:.4f}' for v in vals) + '>'

    def send_arm(self, positions, t_sec=2.0):
        msg = JointTrajectory()
        msg.joint_names = ARM_JOINTS
        pt = JointTrajectoryPoint()
        pt.positions     = positions
        pt.velocities    = [0.0] * len(ARM_JOINTS)
        pt.accelerations = [0.0] * len(ARM_JOINTS)
        pt.time_from_start.sec     = int(t_sec)
        pt.time_from_start.nanosec = int((t_sec % 1) * 1e9)
        msg.points.append(pt)
        self.arm_pub.publish(msg)

    def send_gripper(self, position, t_sec=1.5):
        msg = JointTrajectory()
        msg.joint_names = [GRIPPER_JOINT]
        pt = JointTrajectoryPoint()
        pt.positions     = [position]
        pt.velocities    = [0.0]
        pt.time_from_start.sec = int(t_sec)
        msg.points.append(pt)
        self.gripper_pub.publish(msg)

    def emergency_stop(self):
        self.send_arm(self.arm_pos, t_sec=0.05)
        self.send_gripper(self.gripper_pos, t_sec=0.05)

    def play_sequence(self, loop_count=1):
        if not self.waypoints:
            return False
        msg = JointTrajectory()
        msg.joint_names = ARM_JOINTS
        t = 2.0
        for _ in range(loop_count):
            for wp in self.waypoints:
                pt = JointTrajectoryPoint()
                pt.positions     = wp
                pt.velocities    = [0.0] * len(ARM_JOINTS)
                pt.accelerations = [0.0] * len(ARM_JOINTS)
                pt.time_from_start.sec     = int(t)
                pt.time_from_start.nanosec = int((t % 1) * 1e9)
                msg.points.append(pt)
                t += 2.0
        self.arm_pub.publish(msg)
        return True

    def wait_convergence(self, joint_name, target, tolerance, unit):
        """
        Bloquea el hilo del menú mostrando una barra de progreso hasta que
        el joint llegue a target±tolerance o se agote MOVE_TIMEOUT.
        Retorna (logrado:bool, segundos:float).
        """
        t0 = time.time()
        e0 = abs(self._pos[joint_name] - target)
        if e0 < 1e-6:
            print(f"  [{'█'*20}]  Δ=0.0000 {unit.strip()}  0.0s  ✅ YA EN POSICIÓN")
            return True, 0.0

        while True:
            elapsed = time.time() - t0
            error   = abs(self._pos[joint_name] - target)
            prog    = max(0.0, min(1.0, 1.0 - error / e0))
            bar     = '█' * int(prog * 20) + '░' * (20 - int(prog * 20))

            print(f'\r  [{bar}]  Δ={error:.4f} {unit.strip()}  {elapsed:.1f}s ',
                  end='', flush=True)

            if error < tolerance:
                print(f'\r  [{"█"*20}]  Δ={error:.4f} {unit.strip()}  {elapsed:.1f}s  ✅ LOGRADO')
                return True, elapsed

            if elapsed > MOVE_TIMEOUT:
                print(f'\r  [{bar}]  Δ={error:.4f} {unit.strip()}  ⏱ TIMEOUT ({MOVE_TIMEOUT:.0f}s)')
                return False, elapsed

            time.sleep(0.05)
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

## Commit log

2026-05-11 Estructura inicial de arm_description: XACRO corregido, mimic joints y base_footprint
    [arm_description.xacro, barra_mecanismo.STL, base_link.STL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]
2026-05-17 Diseño 2 del brazo con el pluggin Gazeboros2control y el robot en entorno de simulacion con carga para seleccion de motores
    [Base.STL, Griper.STL, Motor1.STL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]
2026-05-24 Drivers para el robot real
    Driver de prueba para conexión de los motores con la ESP32
2026-05-24 Script de lanzamiento de control para el brazo ymodificación al Xacro para no tener que correr gazebo en la ejecución real
    [Base.STL, Griper.STL, Motor1.STL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]
2026-06-01 Agregadas las configuraciones para los 2 motores faltantes
    [Base.STL, Griper.STL, Motor1.STL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]
2026-06-06 Pruebas agregadas para comunicación con ESP32 y acciones desde la terminal
    [arm_description.xacro]
2026-06-07 Error en archivo xacro, estaba definido para el simulador gazebo
    [arm_description.xacro]
2026-06-07 Error en el launch y el serial bridge con orden correcto
    [arm_description.xacro]
2026-06-07 Error en el launch y el serial bridge con orden correcto 2
2026-06-07 Cambio en la frecuencia de envio al esp32 serial_bridge.py
2026-06-09 Versión final de la interfaz gráfica considerando una primera fase de calibración para el riel
    [arm_description.xacro]
2026-06-13 Errores en el valor de los grados de apertura del gripper
    [arm_controllers.yaml]
2026-06-13 Correción de interfaz para el gripper
2026-06-13 Recepción de trama de esp
2026-06-14 Update and rename driver_esp32.cpp to driver_esp32.ino
2026-06-14 Create README.md for robotic arm project
    Add detailed project documentation for robotic arm control system.
2026-06-18 Update project title to 4 GDL robotic arm
